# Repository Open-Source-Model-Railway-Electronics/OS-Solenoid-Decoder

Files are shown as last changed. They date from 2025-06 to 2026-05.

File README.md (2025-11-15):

# OS-Solenoid-Decoder

The OS-Solenoid-Decoder is a simple, powerful DCC accessory decoder for switching:

• Turnouts (point motors),  
• Relays,  
• Uncouplers,  
• And other solenoid-driven devices.  

It can handle loads of up to 5 amps and supports almost any type of point motor.  
It can also be used in combination with OS-relays to handle frog polarisation for electrofrog and unifrog points.  

This decoder is designed to be:

• Easy to wire — with pluggable screw terminals,  
• Easy to configure — using only standard DCC accessory commands,  
• Modular — with optional relay and transistor expansion boards,  
• And robust — with built-in overload protection.  

Whether you're building a large layout or just want something that works without hassle:  
this decoder is made to get the job done, without needing a degree in electronics.

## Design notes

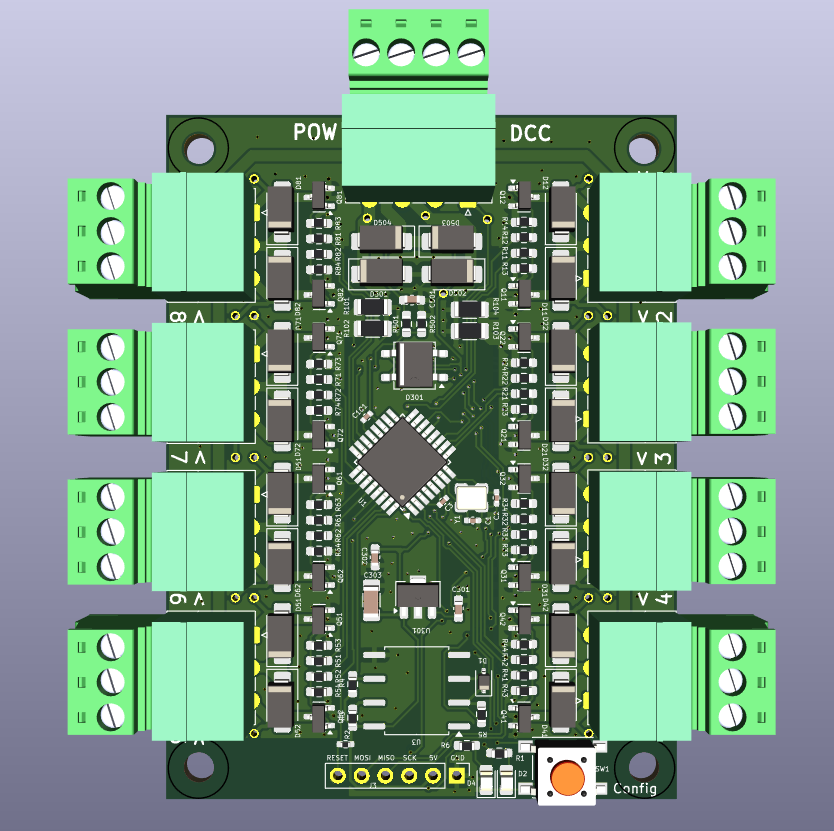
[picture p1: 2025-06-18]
hardware/OS-Solenoid-Decoder.png

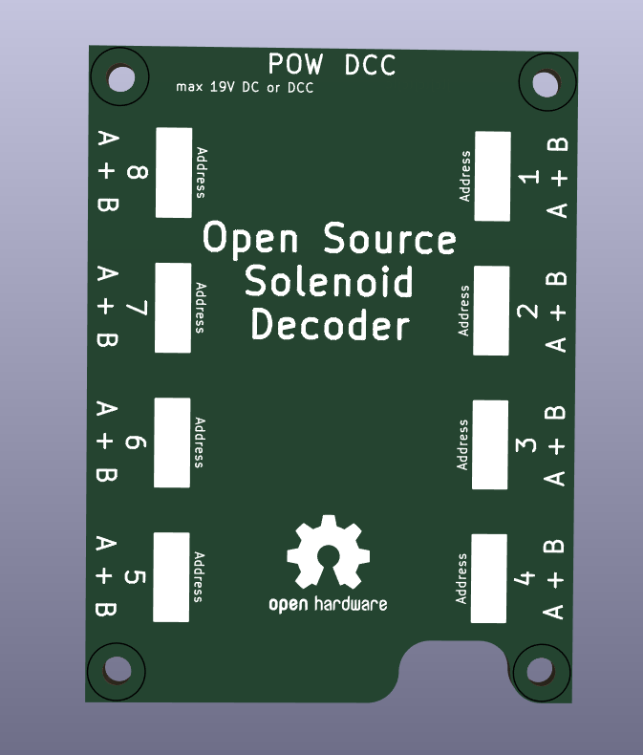
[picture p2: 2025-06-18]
hardware/OS-Solenoid-Decoder2.png

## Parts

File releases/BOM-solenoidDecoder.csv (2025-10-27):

Comment | Designator | Footprint | LCSC
6N137 | U3 | SOP-8_6.62x9.15mm_P2.54mm | C110020
Crystal_GND2 | Y1 | crystal_arduino | C13738
100nF | C302,C501 | C_0603_1608Metric_Pad1.08x0.95mm_HandSolder | C14663
ATmega328-A | U1 | TQFP-32_7x7mm_P0.8mm | C14877
100uF | C303 | C_1206_3216Metric_Pad1.33x1.80mm_HandSolder | C15008
12pF | C1,C2 | C_0402_1005Metric_Pad0.74x0.62mm_HandSolder | C1547
330nF | C301 | C_0603_1608Metric_Pad1.08x0.95mm_HandSolder | C1615
AO3400A | Q11,Q12,Q21,Q22,Q31,Q32,Q41,Q42,Q51,Q52,Q61,Q62,Q71,Q72,Q81,Q82 | SOT-23 | C20917
D | D1 | D_SOD-323 | C2128
1k5 | R5 | R_0603_smalltext | C22843
22R | R11,R12,R21,R22,R31,R32,R41,R42,R51,R52,R61,R62,R71,R72,R81,R82 | R_0603_1608Metric_Pad0.98x0.95mm_HandSolder | C23345
MB10S | D301 | TO-269AA | C2488
0R1 | R101,R102,R103,R104 | R_1206_3216Metric | C25334
10k | R2 | R_0402_1005Metric_Pad0.72x0.64mm_HandSolder | C25744
10k | R1,R13,R14,R23,R24,R3,R33,R34,R4,R43,R44,R502,R53,R54,R63,R64,R73,R74,R83,R84 | R_0603_smalltext | C25804
47k | R501 | R_0603_smalltext | C25819
100nF | C101,C3 | C_0402_1005Metric | C307331
SW_SPST | SW1 | tactile_SMD_6mm | C381050
6k2 | R6 | R_0603_1608Metric_Pad0.98x0.95mm_HandSolder | C4260
L78L05_SOT89 | U301 | SOT-89-3 | C42738
LED | D2,D4 | LED_0805_2012Metric_Pad1.15x1.40mm_HandSolder | C84256
SS34 | D11,D12,D21,D22,D31,D32,D41,D42,D501,D502,D503,D504,D51,D52,D61,D62,D71,D72,D81,D82 | D_SMA | C8678
~ | J11,J21,J31,J41,J51,J61,J71,J81 | PhoenixContact_MC_1,5_3-G-3.5_1x03_P3.50mm_Horizontal | C880573
Screw_Terminal_01x04 | J62 | PhoenixContact_MC_1,5_4-G-3.5_1x04_P3.50mm_Horizontal | C880574

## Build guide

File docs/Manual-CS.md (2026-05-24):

> 🌐 &nbsp; [🇬🇧 EN](Manual-EN.md) &nbsp;|&nbsp; [🇩🇪 DE](Manual-DE.md) &nbsp;|&nbsp; [🇫🇷 FR](Manual-FR.md) &nbsp;|&nbsp; [🇳🇱 NL](Manual-NL.md) &nbsp;|&nbsp; [🇪🇸 ES](Manual-ES.md) &nbsp;|&nbsp; [🇮🇹 IT](Manual-IT.md) &nbsp;|&nbsp; [🇵🇱 PL](Manual-PL.md) &nbsp;|&nbsp; 🇨🇿 CS &nbsp;|&nbsp; [🇩🇰 DA](Manual-DA.md) &nbsp;|&nbsp; [🇳🇴 NO](Manual-NO.md) &nbsp;|&nbsp; [🇸🇪 SV](Manual-SV.md) &nbsp;|&nbsp; [🇭🇺 HU](Manual-HU.md) &nbsp;|&nbsp; [🇵🇹 PT](Manual-PT.md)

# OS-Solenoid-Decoder

## 📘 Úvod

OS-Solenoid-Decoder je jednoduchý, výkonný DCC příslušenský dekodér pro přepínání:

- Výhybek (pohony výhybek)
- Relé
- Odpojovačů
- Jakéhokoli jiného solenoidem řízeného zařízení

Zvládá zatížení až 5 ampér a podporuje téměř jakýkoli typ pohonu výhybky.
Lze jej také kombinovat s OS-relays pro polarizaci srdcovky u výhybek electrofrog i unifrog.

Tento dekodér je navržen jako:

- **Snadný na zapojení** — zásuvné šroubové svorky usnadňují předpřipravení a umožňují rychlé vyjmutí nebo výměnu
- **Snadný na konfiguraci** — používá pouze standardní DCC příslušenské příkazy; bez počítače, bez CV, bez POM
- **Modulární** — volitelné rozšiřující desky relé a tranzistorů
- **Robustní** — vestavěná ochrana proti přetížení

Ať stavíte velké kolejiště nebo chcete jen něco, co funguje bez potíží: tento dekodér je stvořen k tomu, aby splnil úkol.

---

## Obsah

- [Vlastnosti](#-vlastnosti)
- [Připojení dekodéru](#-připojení-dekodéru)
- [Napájení](#-napájení)
- [Solenoidové výstupy](#-solenoidové-výstupy)
- [Relé rozšíření – polarizace Unifrog](#-relé-rozšíření--polarizace-unifrog)
- [Relé rozšíření – polarizace Electrofrog](#-relé-rozšíření--polarizace-electrofrog)
- [Relé rozšíření – otevřený kontakt (víceúčelový)](#️-relé-rozšíření--otevřený-kontakt-víceúčelový)
- [Odpojovače a jiné indukční zátěže](#-odpojovače-a-jiné-indukční-zátěže)
- [Konfigurace OS-Solenoid-Decoder](#️-konfigurace-os-solenoid-decoder)
- [Chování LED v provozním režimu](#-chování-led-v-provozním-režimu)
- [Vstup do konfiguračního režimu](#-vstup-do-konfiguračního-režimu)
- [Než začnete](#-než-začnete)
- [Přehled menu](#-přehled-menu)
- [Menu 1: Přiřazení DCC adres](#-menu-1-přiřazení-dcc-adres)
- [Menu 2: Výběr typu výstupu](#-menu-2-výběr-typu-výstupu)
- [Menu 3: Konfigurace doby impulzu](#-menu-3-konfigurace-doby-impulzu)
- [Menu 4: Pracovní cyklus PWM](#-menu-4-pracovní-cyklus-pwm)
- [Menu 5: Globální nastavení a předvolby](#-menu-5-globální-nastavení-a-předvolby)
- [Vysvětlení ovládání lokomotivními funkcemi](#-vysvětlení-ovládání-lokomotivními-funkcemi)

---

## 🔧 Vlastnosti

- **Celkový výstupní proud až 5 A** — pohání výkonné solenoidy, relé nebo pohony výhybek bez externích zesilovačů
- **Zásuvné šroubové svorky** — usnadňují předpřipravení a umožňují rychlé vyjmutí nebo výměnu dekodéru
- **Více výstupních režimů:**
  - Dvojitý impulz (výchozí)
  - Jednoduchý impulz
  - Dvojitý trvalý
  - Jednoduchý trvalý
  - Dvojitý impulz s relé Electrofrog
- **Jeden výstup najednou** — dekodér přepíná vždy jeden výstupní pár, aby předešel přetížení
- **Volitelná podpora modulu CDU** — snižuje spotřebu energie a prodlužuje životnost pohonu výhybky
- **Detekce a ochrana proti přetížení** — výstupy jsou automaticky deaktivovány při detekci přetížení
- **Konfigurace pouze prostřednictvím DCC příkazů** — není potřeba programovací software ani hardware
- **Předdefinované konfigurační předvolby** — rychle přepněte všechny výstupy na impulzní, trvalý nebo electrofrog režim jediným DCC příkazem
- **Ovládání lokomotivními funkcemi** (F1–F16) — pro rychlé přepínání pomocí ovladačů jako Roco Lokmaus nebo Multimaus
- **Podpora Roco adresového offsetu** — vestavěná podpora pro Roco 4-adresový offset
- **Rozšiřitelné relé a tranzistorovými deskami:**
  - Dvojitý relé modul pro polarizaci výhybky electrofrog
  - Jednoduché aretační relé pro přepínání polarity unifrog
  - Relé moduly s otevřeným kontaktem pro víceúčelové DCC relé ovládání
  - Tranzistorový budič pro dvouvodičové pohony výhybek

---

## 🔌 Připojení dekodéru

OS-Solenoid-Decoder se řídí přehledným a konzistentním schématem zapojení. Napájení je připojeno nahoře, výstupy jsou na obou stranách.

---

## 🔋 Napájení

- Připojte kolejové napětí DCC nebo DC napájení (max. 19 V) k dekodéru.
- Jak DCC signál, tak napájecí vodiče se připojují z horní strany dekodéru.
- ⚠️ Nepoužívejte AC napětí — poškodí dekodér.

---

## ⚡ Solenoidové výstupy

Dekodér poskytuje 8 dvojitých výstupních bloků navržených pro klasické dvousmyčkové pohony výhybek.

Každý výstupní blok má:

- Dvě vnější šroubové svorky — pro levou a pravou cívku (A a B)
- Jednu středovou svorku — pro společný vodič (COM), sdílený mezi oběma cívkami

Toto schéma umožňuje:

- Pohánět až 8 dvousmyčkových pohonů výhybek (např. PECO, Fleischmann, Märklin, Roco, Piko, Hornby)
- Nebo přímo připojit 3-vodičové pohony výhybek jako MTB MP-1

Výstupy jsou seskupeny v párech s jasným označením A, COM a B.

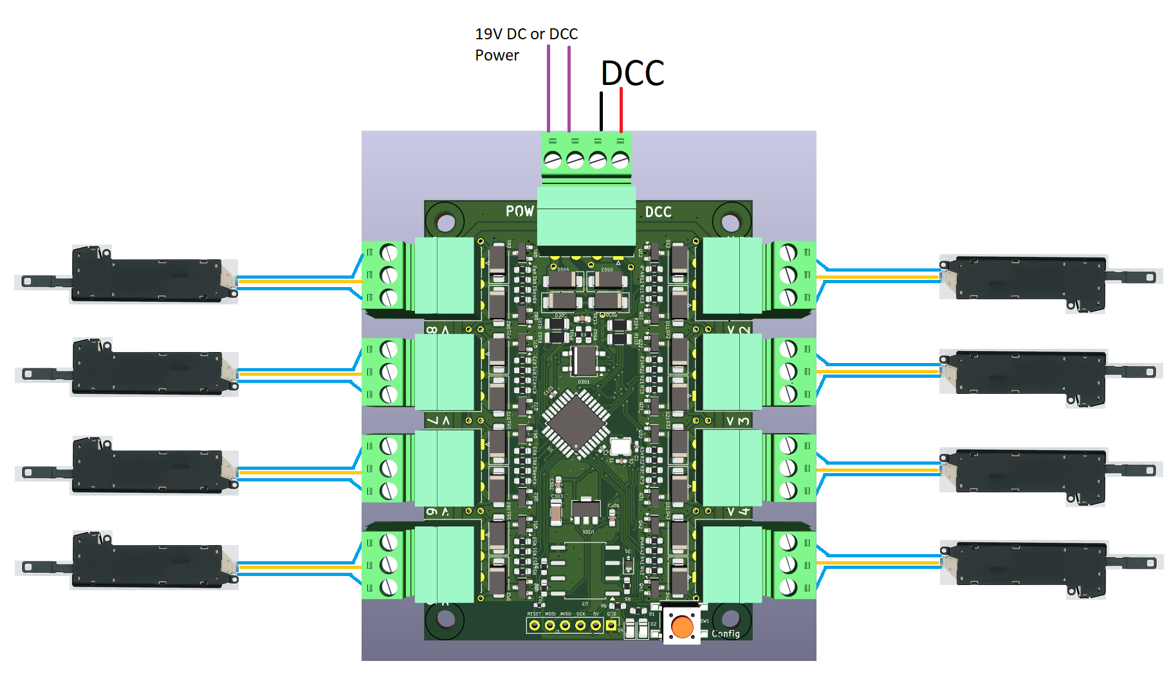
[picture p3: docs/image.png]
Solenoidový dekodér s 8 připojenými dvousmyčkovými pohony výhybek


Ačkoli dekodér není navržen pro ovládání návěstidel, může pohánět jednoduché dvouaspektové návěstidla pomocí stejných výstupů.

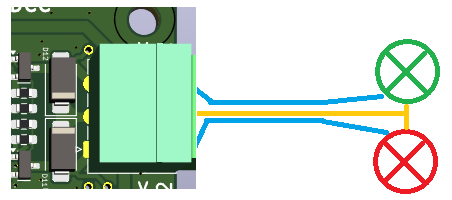
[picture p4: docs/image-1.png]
Příklad zapojení dvouaspektového návěstidla


---

## 🔌 Relé rozšíření – polarizace Unifrog

Toto rozšíření automaticky napájí srdcovku výhybek unifrog pomocí samoaretačních relé.

- Relé deska se skládá ze čtyř malých relé jednotek, které lze odlomit, pokud potřebujete méně než čtyři.

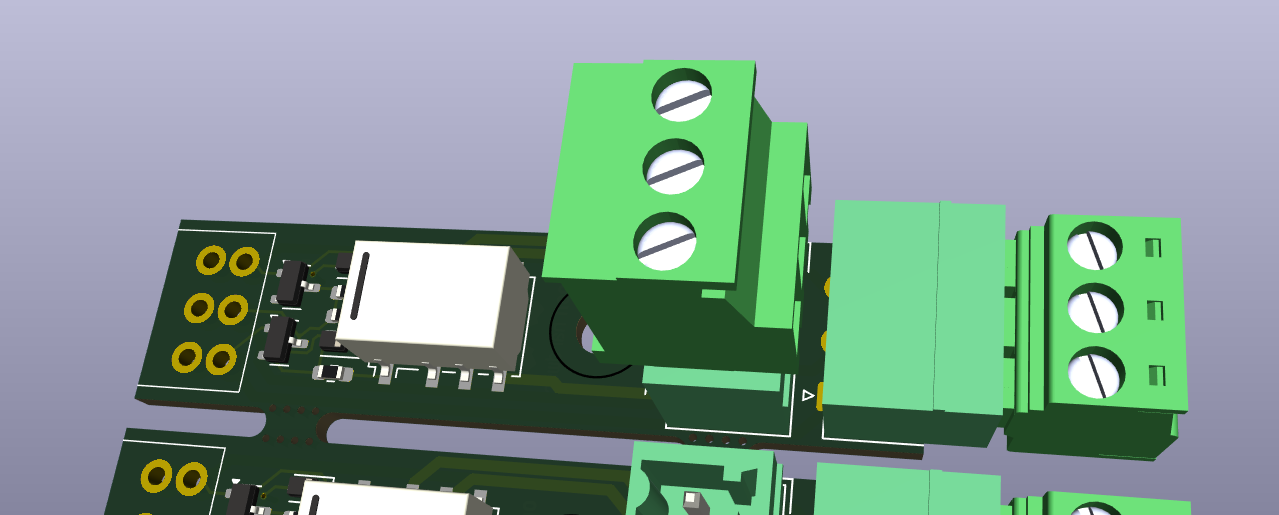
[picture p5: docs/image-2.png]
Aretační relé rozšiřující deska


- Relé jsou aretována stejným signálem, který spouští pohon výhybky — není potřeba žádná extra konfigurace.
- Každá relé jednotka přepíná polaritu srdcovky podle směru výhybky.

S jedním relé na výhybku toto rozšíření zvládá až 8 srdcovek unifrog pomocí dvou desek.

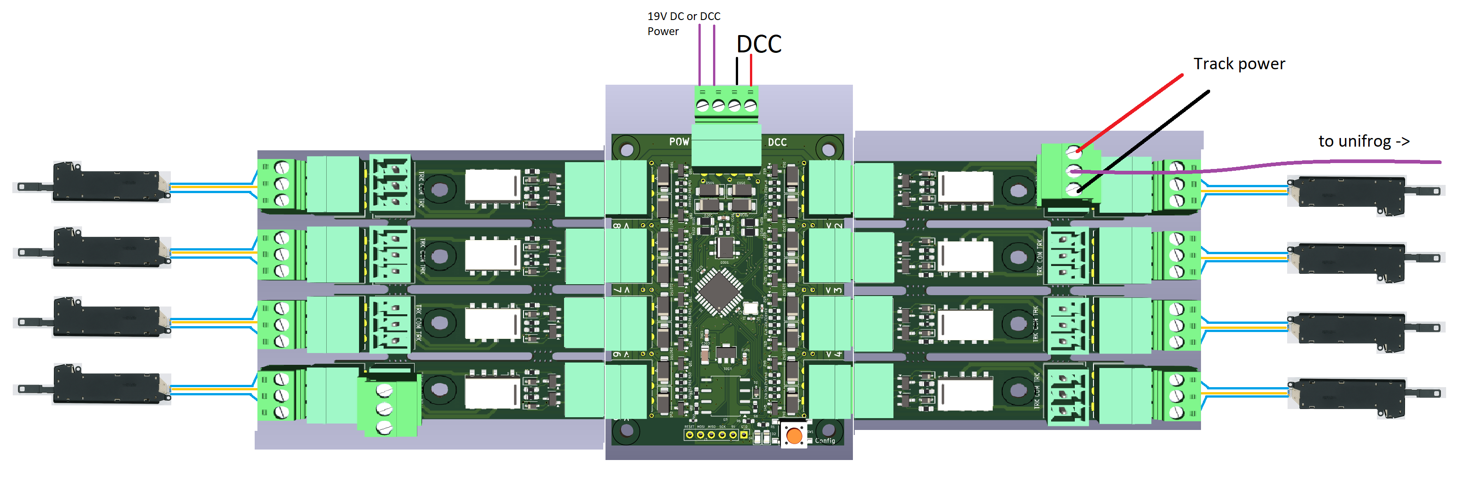
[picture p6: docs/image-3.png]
Relé rozšíření namontované na dekodér pro zapojení unifrog


- Relé deska se přímo zapojuje do rozšiřovacího záhlaví dekodéru, ale lze ji také namontovat vzdáleně poblíž výhybky.

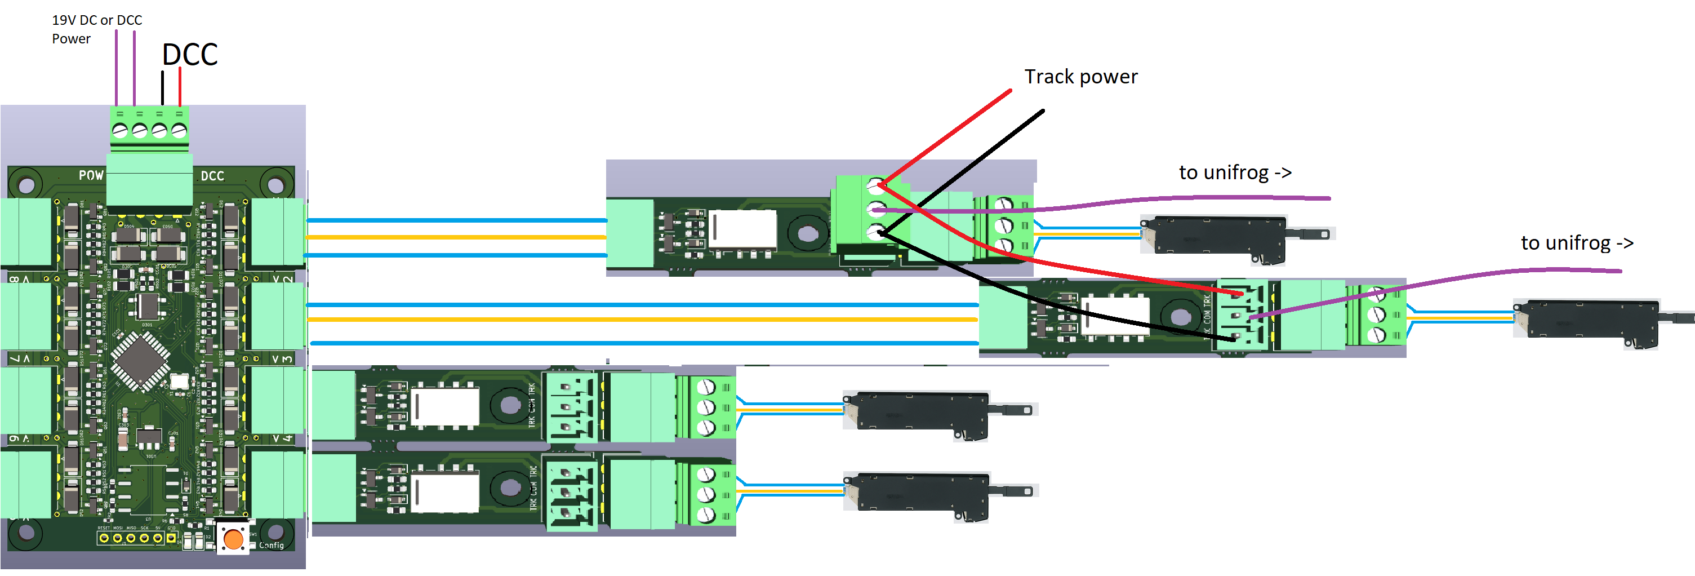
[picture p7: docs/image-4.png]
Příklad vzdáleně namontovaného relé rozšíření


Tento relé modul je také kompatibilní s jinými solenoidovými dekodéry.

---

## ⚡ Relé rozšíření – polarizace Electrofrog

Výhybky Electrofrog vyžadují dvě relé spínací operace na výhybku:

1. Jedno pro odpojení srdcovky před přehozením pohonu výhybky
2. Jedno pro opětovné připojení se správnou polaritou poté

Toto rozšíření zpracovává tuto sekvenci automaticky. Skládá se ze čtyř dvojitých relé modulů, trvale propojených.

- Zapojuje se do levé strany dekodéru (označené pro použití s electrofrog).
- Každý pár relé je propojen s jedním solenoidovým výstupem: výstup 1 → pár relé 1, výstup 2 → pár relé 2 atd.
- Tyto moduly nelze oddělovat, protože sdílejí kolejové napájení a interní logiku.

Dekodér má speciální předvolbu, která aktivuje přepínací sekvenci electrofrog.
Pokud je polarita srdcovky po instalaci nesprávná, obraťte přepínače na relé modulu pro opravu — není potřeba žádné přeprogramování.

---

## ⚙️ Relé rozšíření – otevřený kontakt (víceúčelový)

Pro přepínání externích zařízení (světla, návěstidla, logické obvody) pomocí prostých relé kontaktů:

- Každá jednotka poskytuje přepínací (NO/NC) relé, ovládatelné přes DCC.
- Až 16 individuálně adresovatelných relé kontaktů při plném osazení.
- Moduly se přímo zapojují do dekodéru nebo lze je použít vzdáleně s vodiči.
- Dostupné ve verzi s průchozím montáží pro kutily a v kompaktní verzi SMD.

Stejně jako relé desky unifrog lze tyto moduly odlomit a znovu použít s jinými DCC solenoidovými dekodéry.

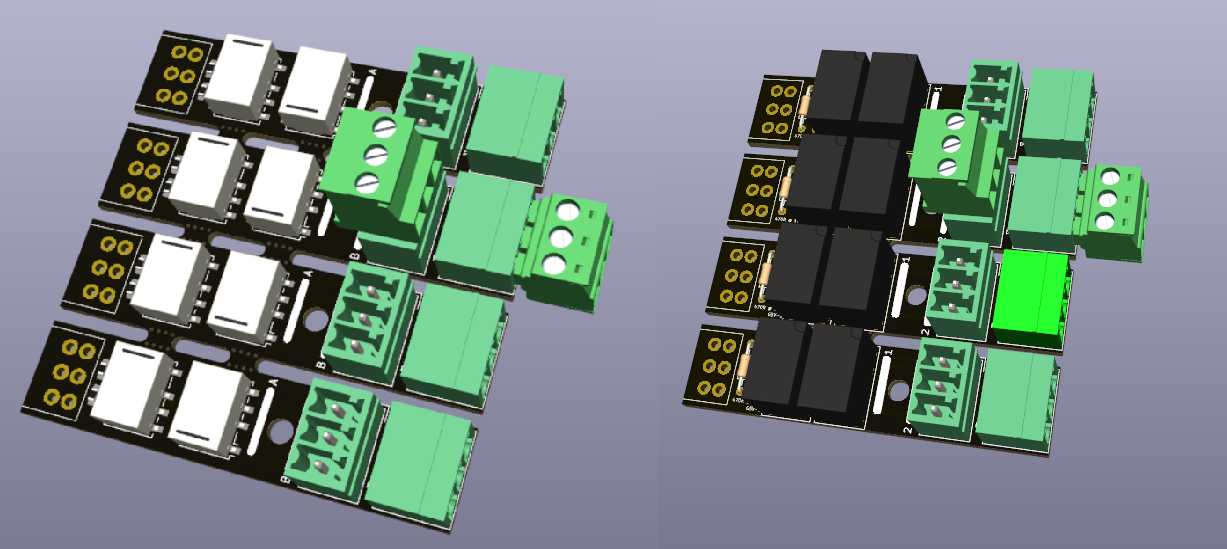
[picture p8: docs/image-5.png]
Víceúčelové relé moduly namontované na dekodér


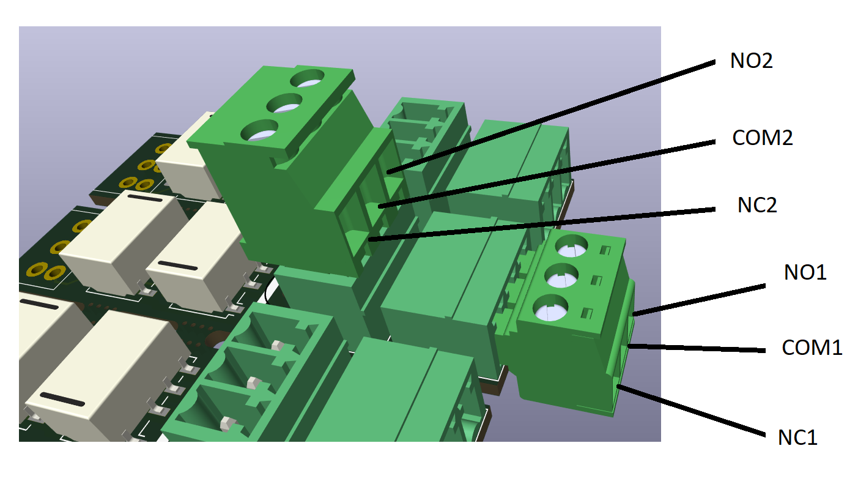
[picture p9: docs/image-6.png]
Detail víceúčelového relé modulu


Víceúčelové relé rozšíření může také polarizovat výhybky electrofrog s mírně složitějším zapojením:

- Použijte kontakty NO (Normally Open)
- Propojte oba kontakty COM dohromady a připojte je ke srdcovce
- Připojte kontakty NO k napájecím kolejnicím

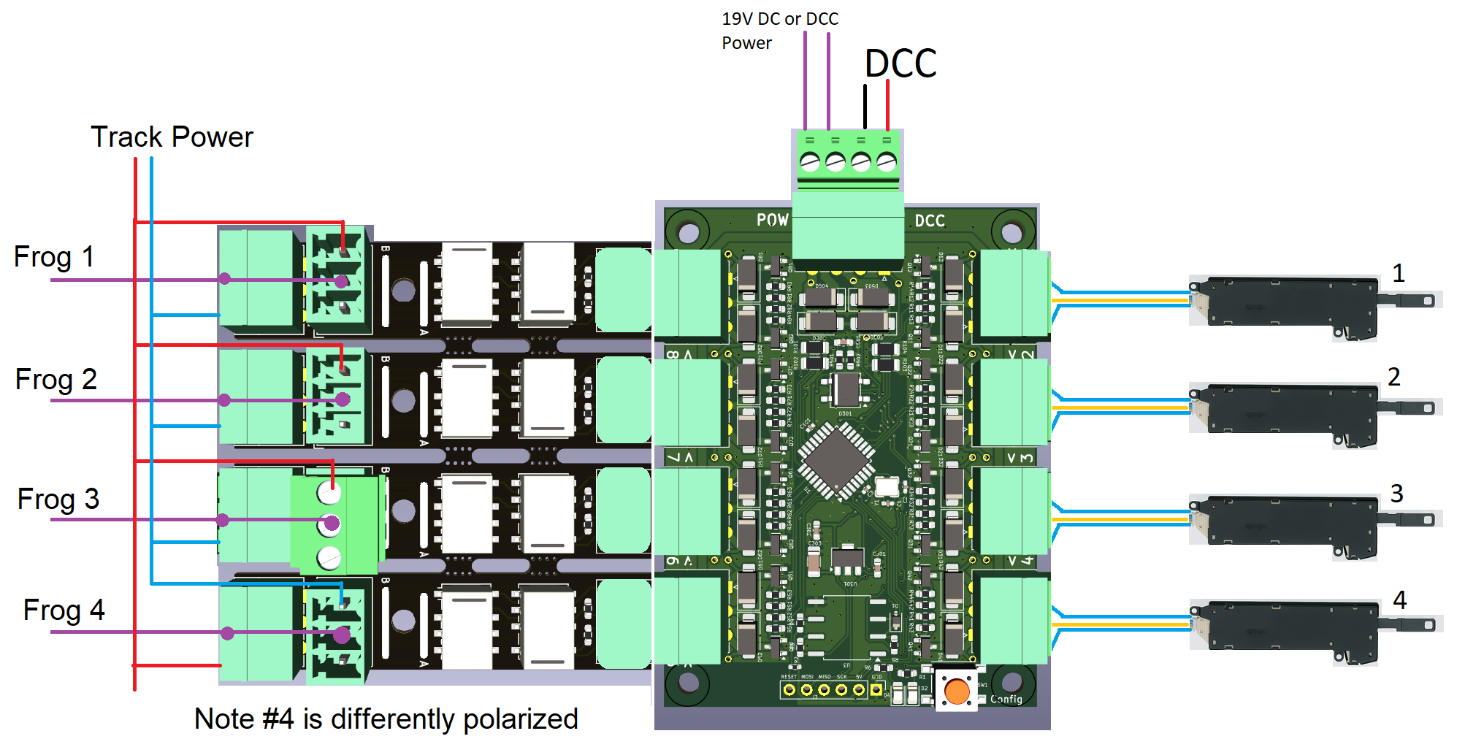
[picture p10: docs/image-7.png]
Zapojení electrofrog pomocí víceúčelových relé modulů


Pokud má srdcovka nesprávnou polaritu, prohoďte dva napájecí vodiče kolejnic (jak je znázorněno pro srdcovku 4 ve výše uvedeném schématu).

---

## 🧲 Odpojovače a jiné indukční zátěže

OS-Solenoid-Decoder může pohánět odpojovače, elektromagnety a jiné indukční zátěže kromě pohonů výhybek.

- **Režim jednoduchého impulzu** (doporučeno) — vysílá krátký proud, ideální pro cívky s pružinou nebo časově citlivé cívky
- **Režim jednoduchého trvalého** — udržuje výstup trvale zapnutý, užitečné pro monostabilní relé nebo jednoduché ZAP/VYP zařízení

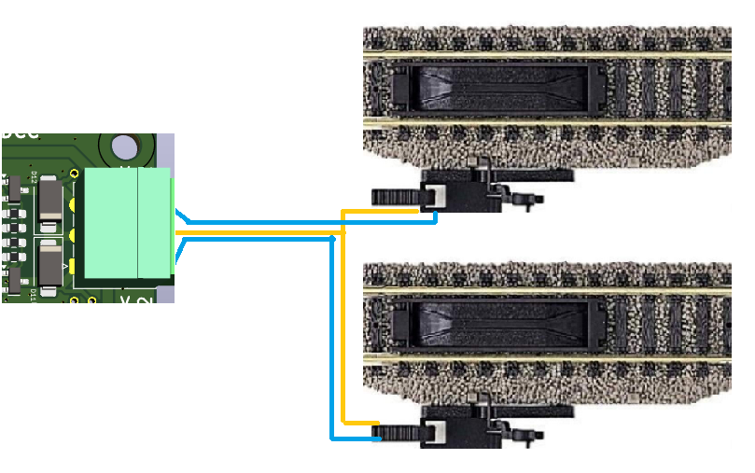
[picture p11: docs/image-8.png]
Příklad zapojení odpojovače


⚠️ Odpojovače se mohou přehřát při příliš dlouhém přepnutí — vždy kontrolujte datový list pro vaši značku koleje a udržujte dobu impulzu krátkou.

---

## ⚙️ Konfigurace OS-Solenoid-Decoder

Ve výchozím stavu dekodér pracuje v normálním režimu při zapnutí. Dvě LED poskytují vizuální zpětnou vazbu o tom, co se děje.

---

## 🔦 Chování LED v provozním režimu

| Vzor LED | Režim |
|---|---|
| Obě LED blikají | Dvojitý impulz (výchozí) |
| Jedna LED bliká, druhá ZHASNUTÁ | Jednoduchý impulz |
| Obě LED SVÍTÍ | Dvojitý trvalý |
| Jedna LED SVÍTÍ | Jednoduchý trvalý |
| Jedna LED SVÍTÍ + druhá LED bliká | Režim Electrofrog (dvojitý impulz + relé srdcovky) |

Pokud jsou výstupy nakonfigurovány se smíšenými typy, levá LED zůstane SVÍTIT a pravá LED bude nepřetržitě jednou blikat, aby indikovala smíšený konfigurační režim.

---

## 🧰 Vstup do konfiguračního režimu

Pro vstup do konfiguračního režimu:

1. Podržte konfigurační tlačítko. Pravá LED začne blikat:
   - 1 bliknutí = Menu 1
   - 2 bliknutí = Menu 2
   - ... až do Menu 5
2. Uvolněte tlačítko, když LED dosáhne požadovaného menu.

Po vstupu do menu:

- Levá LED bliká stejný počet bliknutí jako číslo menu (např. 3 bliknutí = Menu 3).
- Stiskněte tlačítko znovu pro ukončení menu, pokud níže uvedená sekce neříká jinak.

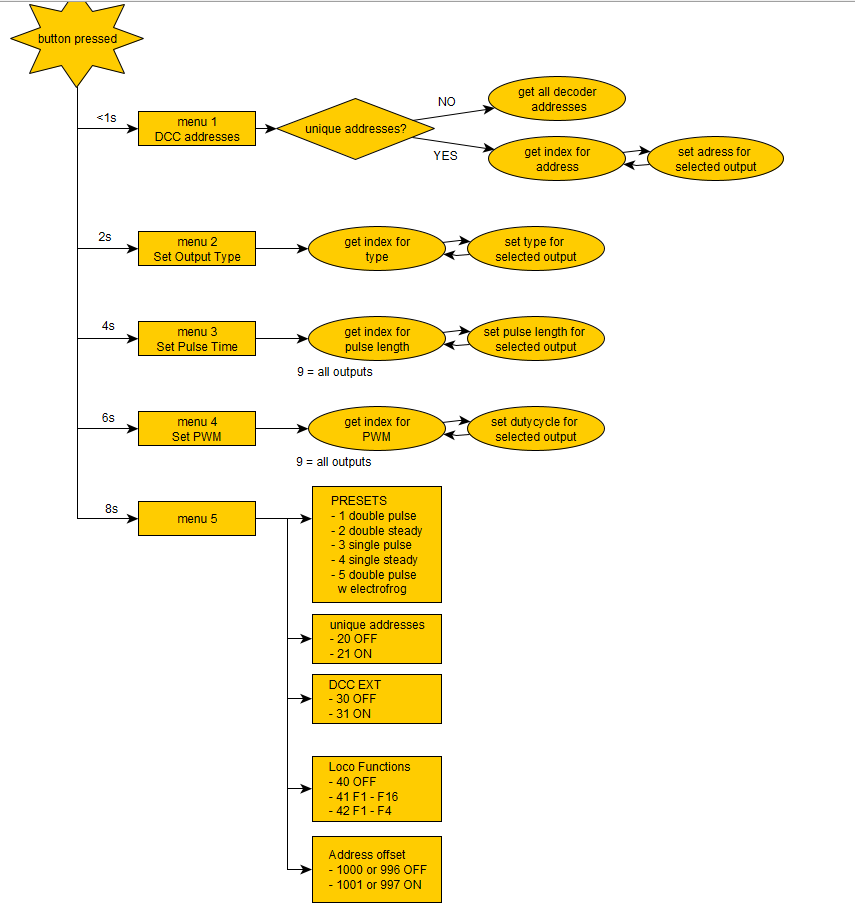
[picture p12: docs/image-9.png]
Vývojový diagram konfiguračního menu


---

## 🧠 Než začnete

Pokud plánujete používat smíšené typy výstupů (např. Jednoduchý trvalý pro relé vedle Dvojitého impulzu pro pohony výhybek), naplánujte si přiřazení výstupů nejprve na papíře.

**Příklad:** pokud výstupy 5–8 mají být Jednoduchý trvalý (pro 8 relé) a výstupy 1–4 mají být Dvojitý trvalý (pro pohony výhybek), musíte:

1. Použít Menu 2 pro přiřazení správných typů výstupů
2. Poté použít Menu 1 pro pečlivé přiřazení DCC adres, protože jednoduché výstupy používají více adres

---

## 📖 Přehled menu

| Menu | Funkce |
|---|---|
| 1 | Přiřazení DCC adres |
| 2 | Výběr typu výstupu |
| 3 | Konfigurace doby impulzu |
| 4 | Pracovní cyklus PWM |
| 5 | Globální nastavení a předvolby |

---

## 🟠 Menu 1: Přiřazení DCC adres

Toto menu slouží k přiřazení DCC adres každému výstupu.

Pravidla:
- Dvojité režimy používají 1 adresu
- Jednoduché režimy používají 2 adresy (A a B samostatně)

Pokud přiřadíte adresu 20 k výstupu 1 v jednoduchém režimu, zabere adresy 20 a 21. Výstup 2 pak začne na adrese 22. Dekodér toto posouvání zpracovává automaticky.

Výběr výstupů:
- Odešlete DCC příslušenskou adresu 1–8 pro výběr výstupu.
- Odešlete druhou adresu pro přiřazení k danému výstupu.
- Odešlete adresu 9 jako volič pro okamžité použití stejné adresy na všechny výstupy.

V režimu jedinečného adresování můžete přiřadit každému výstupu vlastní adresu včetně opakovaných nebo přeskočených čísel. Dekodér se okamžitě vrátí do provozního režimu po přiřazení, pokud není aktivní jedinečný režim — v tom případě stiskněte konfigurační tlačítko pro ukončení.

---

## 🟡 Menu 2: Výběr typu výstupu

Každý výstup lze nastavit na jeden z následujících typů:

| ID typu | Popis režimu |
|---|---|
| 1 | Dvojitý impulz (výchozí) |
| 2 | Dvojitý trvalý |
| 3 | Jednoduchý impulz |
| 4 | Jednoduchý trvalý |
| 5 | Dvojitý impulz s podporou relé Electrofrog |

V režimu Electrofrog ovládají výstupy 1–4 páry relé na výstupech 8–5 v opačném pořadí (výstup 1 → relé 8, výstup 2 → relé 7 atd.).

Vyberte výstup ke konfiguraci odesláním DCC adresy 1–8.

---

## 🔵 Menu 3: Konfigurace doby impulzu

Doladění doby impulzu pro každý výstup.

**Výstupy s jednoduchým impulzem:**
- Čas se nastavuje v celých sekundách
- Adresa 10 = 10 sekund
- Rozsah: 1–4096 sekund
- Výchozí: 5 s

**Výstupy s dvojitým impulzem:**
- Čas se nastavuje v krocích po 10 ms
- Adresa 1 = 10 ms
- Maximum: 40,9 s (4096 × 10 ms)
- Výchozí: 50 ms

Odešlete adresu 9 pro okamžité použití stejného času na všechny výstupy.

---

## 🟣 Menu 4: Pracovní cyklus PWM

Dostupné pro výstupy nakonfigurované v trvalém režimu (jednoduchém nebo dvojitém).

PWM snižuje průměrný dodávaný výkon — ideální pro pomalé motory jako MTB MP-1.

- Frekvence PWM: 50 Hz
- Adresa 10 = 100% pracovní cyklus (výchozí; plný výkon, bez PWM)

| Adresa | Pracovní cyklus |
|---|---|
| 1 | 10 % |
| 2 | 20 % |
| ... | ... |
| 10 | 100 % (výchozí) |

Odešlete adresu 9 pro použití stejného pracovního cyklu na všechny výstupy.

---

## 🔘 Menu 5: Globální nastavení a předvolby

**Předvolby — nastavení všech typů výstupů najednou:**

| Adresa | Předvolba |
|---|---|
| 1 | Dvojitý impulz (výchozí) |
| 2 | Dvojitý trvalý |
| 3 | Jednoduchý impulz |
| 4 | Jednoduchý trvalý |
| 5 | Dvojitý impulz s režimem Electrofrog |

**Speciální možnosti:**

| Adresa | Nastavení |
|---|---|
| 20 | Zakázat jedinečné adresy výstupů (výchozí) |
| 21 | Povolit jedinečné adresy výstupů |
| 30 | Zakázat podporu příkazů DCC EXT (výchozí) |
| 31 | Povolit podporu délky impulzu DCC EXT |
| 40 | Zakázat ovládání lokomotivními funkcemi (výchozí) |
| 41 | Povolit lokomotivní funkce (F1–F16, 1 adresa) |
| 42 | Povolit lokomotivní funkce (F1–F4, 2+ adresy) |
| 996 / 1000 | Zakázat Roco 4-adresový offset (výchozí) |
| 997 / 1001 | Povolit Roco 4-adresový offset |

---

## 📟 Vysvětlení ovládání lokomotivními funkcemi

Dekodér lze ovládat pomocí funkčních kláves lokomotivy (F1–F16) místo DCC příslušenských příkazů.

**Výhody:**
- Funguje s ovladači jako Roco Lokmaus 2
- Velmi rychlé přepínání — ideální pro rychlé ovládání kolejiště

**Režimy:**
- **Režim F1–F16:** používá 1 adresu lokomotivy
- **Režim F1–F4:** používá 2 nebo více adres lokomotivy (užitečné pro ovladače, které podporují pouze F1–F4)

Použitá adresa lokomotivy odpovídá DCC adrese přiřazené k výstupu 1.

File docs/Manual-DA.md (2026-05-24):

> 🌐 &nbsp; [🇬🇧 EN](Manual-EN.md) &nbsp;|&nbsp; [🇩🇪 DE](Manual-DE.md) &nbsp;|&nbsp; [🇫🇷 FR](Manual-FR.md) &nbsp;|&nbsp; [🇳🇱 NL](Manual-NL.md) &nbsp;|&nbsp; [🇪🇸 ES](Manual-ES.md) &nbsp;|&nbsp; [🇮🇹 IT](Manual-IT.md) &nbsp;|&nbsp; [🇵🇱 PL](Manual-PL.md) &nbsp;|&nbsp; [🇨🇿 CS](Manual-CS.md) &nbsp;|&nbsp; 🇩🇰 DA &nbsp;|&nbsp; [🇳🇴 NO](Manual-NO.md) &nbsp;|&nbsp; [🇸🇪 SV](Manual-SV.md) &nbsp;|&nbsp; [🇭🇺 HU](Manual-HU.md) &nbsp;|&nbsp; [🇵🇹 PT](Manual-PT.md)

# OS-Solenoid-Decoder

## 📘 Introduktion

OS-Solenoid-Decoder er en enkel, kraftfuld DCC-tilbehørsdekoder til skift af:

- Sporskifter (sporskiftemotorer)
- Relæer
- Afkoblere
- Enhver anden solenoid-drevet enhed

Den kan håndtere belastninger på op til 5 A og understøtter næsten enhver type sporskiftemotor.
Den kan også bruges i kombination med OS-relæer til at håndtere hjertestykke-polarisering for både Electrofrog- og Unifrog-sporskifter.

Denne dekoder er designet til at være:

- **Nem at kabelforbinde** — tilsluttbare skrueterminaler gør forudkabeltrækning ligetil og muliggør hurtig fjernelse eller udskiftning
- **Nem at konfigurere** — bruger udelukkende standard DCC-tilbehørskommandoer; ingen computer, ingen CV, ingen POM
- **Modulær** — valgfrie relæ- og transistorudvidelseskort
- **Robust** — indbygget overbelastningsbeskyttelse

Uanset om du bygger et stort anlæg eller bare ønsker noget, der fungerer uden besvær: denne dekoder er lavet til at klare opgaven.

---

## Indholdsfortegnelse

- [Egenskaber](#-egenskaber)
- [Tilslutning af dekoderen](#-tilslutning-af-dekoderen)
- [Strømforsyning](#-strømforsyning)
- [Solenoid-udgange](#-solenoid-udgange)
- [Relæudvidelse – Unifrog-polarisering](#-relæudvidelse--unifrog-polarisering)
- [Relæudvidelse – Electrofrog-polarisering](#-relæudvidelse--electrofrog-polarisering)
- [Relæudvidelse – Åben kontakt (general purpose)](#️-relæudvidelse--åben-kontakt-general-purpose)
- [Afkoblere og andre induktive belastninger](#-afkoblere-og-andre-induktive-belastninger)
- [Konfiguration af OS-Solenoid-Decoder](#️-konfiguration-af-os-solenoid-decoder)
- [LED-adfærd i driftstilstand](#-led-adfærd-i-driftstilstand)
- [Adgang til konfigurationstilstand](#-adgang-til-konfigurationstilstand)
- [Inden du starter](#-inden-du-starter)
- [Menooversigt](#-menooversigt)
- [Menu 1: DCC-adressetildeling](#-menu-1-dcc-adressetildeling)
- [Menu 2: Udgangstypevalg](#-menu-2-udgangstypevalg)
- [Menu 3: Pulstidskonfiguration](#-menu-3-pulstidskonfiguration)
- [Menu 4: PWM-arbejdscyklus](#-menu-4-pwm-arbejdscyklus)
- [Menu 5: Globale indstillinger og forudindstillinger](#-menu-5-globale-indstillinger-og-forudindstillinger)
- [Lokomotivfunktionsstyring forklaret](#-lokomotivfunktionsstyring-forklaret)

---

## 🔧 Egenskaber

- **Op til 5 A samlet udgangsstrøm** — driver tunge solenoider, relæer eller sporskiftemotorer uden eksterne boostere
- **Tilsluttbare skrueterminaler** — gør forudkabeltrækning nem og muliggør hurtig fjernelse eller udskiftning af dekoderen
- **Flere udgangstyper:**
  - Dobbelt puls (standard)
  - Enkelt puls
  - Dobbelt stabil
  - Enkelt stabil
  - Dobbelt puls med Electrofrog-relæ
- **Én udgang ad gangen** — dekoderen skifter ét udgangssæt ad gangen for at forhindre overbelastning
- **Valgfri CDU-modulunderstøttelse** — reducerer strømforbrug og forlænger sporskiftemotorens levetid
- **Overbelastningsdetektion og -beskyttelse** — udgange deaktiveres automatisk, hvis en overbelastning registreres
- **Konfiguration udelukkende via DCC-kommandoer** — ingen programmeringssoftware eller hardware påkrævet
- **Foruddefinerede konfigurationsforudindstillinger** — skift hurtigt alle udgange til puls-, stabil- eller Electrofrog-tilstand med en enkelt DCC-kommando
- **Lokomotivfunktionsstyring** (F1–F16) — til hurtig skift via styrenheder som Roco Lokmaus eller Multimaus
- **Roco-adresseforskydningsunderstøttelse** — indbygget understøttelse af Roco 4-adresse-forskydning
- **Udvidelsesmuligheder med relæ- og transistorkort:**
  - Dobbelt relæmodul til Electrofrog-sporskifte-polarisering
  - Enkelt selvholdende relæ til Unifrog-polaritetsskift
  - Åben-kontakt relæmoduler til general-purpose DCC-relæstyring
  - Transistordrivermodul til 2-trådede sporskiftemotorer

---

## 🔌 Tilslutning af dekoderen

OS-Solenoid-Decoder følger et klart og konsistent kabeltrækningslayout. Strøm tilsluttes øverst, udgange er på begge sider.

---

## 🔋 Strømforsyning

- Forbind enten DCC-skinnesænkning eller en DC-strømforsyning (maks. 19 V) til dekoderen.
- Både DCC-signalet og strømleredningerne tilsluttes fra dekodernes øverste side.
- ⚠️ Brug ikke AC-spænding — dette vil beskadige dekoderen.

---

## ⚡ Solenoid-udgange

Dekoderen leverer 8 dobbelte udgangsblokke, designet til klassiske toviklings-sporskiftemotorer.

Hvert udgangsblok har:

- To ydre skrueterminaler — til venstre og højre spole (A og B)
- Én midterterminal — til den fælles ledning (COM), delt mellem de to spoler

Dette layout giver dig mulighed for:

- At drive op til 8 toviklings-sporskiftemotorer (f.eks. PECO, Fleischmann, Märklin, Roco, Piko, Hornby)
- Eller forbinde 3-trådede sporskiftemotorer som MTB MP-1 direkte

Udgange er grupperet i par med klar A-, COM- og B-mærkning.

Solenoid-dekoder med 8 toviklings-sporskiftemotorer tilsluttet

Selvom dekoderen ikke er designet til signalstyring, kan den drive simple to-aspekt-signaler ved hjælp af de samme udgange.

Kabeltrækningseksempel for to-aspekt-signal

---

## 🔌 Relæudvidelse – Unifrog-polarisering

Denne udvidelse forsyner automatisk hjertestykket i Unifrog-sporskifter ved hjælp af selvholdende relæer.

- Relækortet består af fire små relæenheder, som kan knækkes fra hinanden, hvis du har brug for færre end fire.

Selvholdende relæudvidelseskort

- Relæerne aktiveres af det samme signal, der bruges til at udløse sporskiftemotoren — ingen ekstra konfiguration er nødvendig.
- Hver relæenhed skifter hjertestykke-polariteten baseret på sporskiftets retning.

Med ét relæ per sporskifte håndterer denne udvidelse op til 8 Unifrog-hjertestykker ved hjælp af to kort.

Relæudvidelse monteret på dekoder til Unifrog-kabeltrækning

- Relækortet sættes direkte ind i dekodernes udvidelsesheader, men kan også monteres eksternt nær sporskiftet.

Eksempel på eksternt monteret relæudvidelse

Dette relæmodul er også kompatibelt med andre solenoid-dekodere.

---

## ⚡ Relæudvidelse – Electrofrog-polarisering

Electrofrog-sporskifter kræver to relæskift per sporskifte:

1. Ét til at afbryde hjertestykket inden skift af sporskiftemotoren
2. Ét til at genoprette forbindelsen med den korrekte polaritet bagefter

Denne udvidelse håndterer den sekvens automatisk. Den består af fire dobbelte relæmoduler, der er permanent forbundne.

- Det sættes ind i venstre side af dekoderen (markeret til Electrofrog-brug).
- Hvert relæpar er koblet til én solenoid-udgang: udgang 1 → relæpar 1, udgang 2 → relæpar 2 osv.
- Disse moduler kan ikke adskilles, da de deler skinnestrøm og intern logik.

Dekoderen har en særlig forudindstillings-tilstand, der aktiverer Electrofrog-skiftsekvensen.
Hvis hjertestykke-polariteten er forkert efter installation, vend jumberne på relæmodulet for at rette det — ingen omprogrammering er nødvendig.

---

## ⚙️ Relæudvidelse – Åben kontakt (general purpose)

Til skift af eksterne enheder (lys, signaler, logikkredsløb) ved hjælp af rene relækontakter:

- Hver enhed leverer et dobbeltskift (NO/NC)-relæ, der kan styres via DCC.
- Op til 16 individuelt adresserbare relækontakter ved fuld bestyckning.
- Modulerne sættes direkte ind i dekoderen eller kan bruges eksternt med ledninger.
- Tilgængelig i en gennemhuls-DIY-version og en kompakt SMD-version.

Ligesom Unifrog-relækortene kan disse moduler knækkes fra hinanden og genbruges med andre DCC-solenoid-dekodere.

General-purpose relæmoduler monteret på dekoderen

Detail af general-purpose relæmodul

General Purpose-relæudvidelsen kan også polarisere Electrofrog-sporskifter med lidt mere kabeltrækning:

- Brug NO (Normally Open)-kontakterne
- Sæt begge COM-kontakter i sløjfe og forbind dem til hjertestykket
- Forbind NO-kontakterne til skinnestrømsshinnerne

Electrofrog-kabeltrækning ved hjælp af General Purpose-relæmoduler

Hvis et hjertestykke ender med forkert polaritet, byt de to skinnestrømsleredninger (som vist for hjertestykke 4 i diagrammet ovenfor).

---

## 🧲 Afkoblere og andre induktive belastninger

OS-Solenoid-Decoder kan drive afkoblere, elektromagneter og andre induktive belastninger ud over sporskiftemotorer.

- **Enkelt puls-tilstand** (anbefalet) — sender et kort strømudbrud, ideelt til fjederspændte eller tidsfølsomme spoler
- **Enkelt stabil-tilstand** — holder udgangen kontinuerligt tændt, nyttigt til monostabile relæer eller simple TIL/FRA-enheder

Afkoblerkabeltrækningseksempel

⚠️ Afkoblere kan overophede, hvis de tændes for længe — tjek altid dataarket for dit sporvarebrands og hold pulstiderne korte.

---

## ⚙️ Konfiguration af OS-Solenoid-Decoder

Som standard fungerer dekoderen i normal tilstand, når den tændes. To LED'er giver visuel tilbagemelding om, hvad der sker.

---

## 🔦 LED-adfærd i driftstilstand

| LED-mønster | Tilstand |
|---|---|
| Begge LED'er blinker | Dobbelt puls (standard) |
| Én LED blinker, én SLUKKET | Enkelt puls |
| Begge LED'er TÆNDt | Dobbelt stabil |
| Én LED TÆNDt | Enkelt stabil |
| Én LED TÆNDt + anden LED blinker | Electrofrog-tilstand (dobbelt puls + frog-relæ) |

Når udgange er konfigureret med blandede typer, forbliver venstre LED TÆNDt og højre LED blinker én gang kontinuerligt for at angive blandet-konfigurationstilstand.

---

## 🧰 Adgang til konfigurationstilstand

For at gå ind i konfigurationstilstand:

1. Hold konfigurationsknappen nede. Højre LED begynder at blinke:
   - 1 blink = Menu 1
   - 2 blink = Menu 2
   - ... op til Menu 5
2. Slip knappen, når LED'en når den menu, du ønsker.

Når du er i en menu:

- Venstre LED blinker det samme antal gange som menunummeret (f.eks. 3 blink = Menu 3).
- Tryk på knappen igen for at afslutte menuen, medmindre afsnittet nedenfor siger andet.

Konfigurationsmenu-flowdiagram

---

## 🧠 Inden du starter

Hvis du planlægger at bruge blandede udgangstyper (f.eks. Enkelt stabil til relæer sammen med Dobbelt puls til sporskiftemotorer), planlæg dine udgangstildelinger på papir først.

**Eksempel:** Hvis udgange 5–8 skal være Enkelt stabil (til 8 relæer) og udgange 1–4 skal være Dobbelt stabil (til sporskiftemotorer), skal du:

1. Bruge Menu 2 til at tildele de korrekte udgangstyper
2. Derefter bruge Menu 1 til omhyggeligt at tildele DCC-adresser, fordi enkeltudgange bruger flere adresser

---

## 📖 Menooversigt

| Menu | Funktion |
|---|---|
| 1 | DCC-adressetildeling |
| 2 | Udgangstypevalg |
| 3 | Pulstidskonfiguration |
| 4 | PWM-arbejdscyklus |
| 5 | Globale indstillinger og forudindstillinger |

---

## 🟠 Menu 1: DCC-adressetildeling

Brug denne menu til at tildele DCC-adresser til hver udgang.

Regler:
- Dobbelte tilstande bruger 1 adresse
- Enkle tilstande bruger 2 adresser (A og B separat)

Hvis du tildeler adresse 20 til udgang 1 i enkelt tilstand, vil den optage adresserne 20 og 21. Udgang 2 starter derefter ved 22. Dekoderen håndterer denne forskydning automatisk.

Valg af udgange:
- Send DCC-tilbehørsadresse 1–8 for at vælge en udgang.
- Send en anden adresse for at tildele den til den pågældende udgang.
- Send adresse 9 som vælger for at anvende den samme adresse på alle udgange på én gang.

I unik adresseringstilstand kan du give hver udgang en brugerdefineret adresse, herunder gentagne eller udeladte numre. Dekoderen vender tilbage til driftstilstand umiddelbart efter tildeling, medmindre unik tilstand er aktiv — i så fald tryk på konfigurationsknappen for at afslutte.

---

## 🟡 Menu 2: Udgangstypevalg

Hver udgang kan indstilles til en af følgende typer:

| Type-ID | Tilstandsbeskrivelse |
|---|---|
| 1 | Dobbelt puls (standard) |
| 2 | Dobbelt stabil |
| 3 | Enkelt puls |
| 4 | Enkelt stabil |
| 5 | Dobbelt puls med Electrofrog-relæunderstøttelse |

I Electrofrog-tilstand styrer udgange 1–4 relæparrene på udgange 8–5 i omvendt rækkefølge (udgang 1 → relæ 8, udgang 2 → relæ 7 osv.).

Vælg hvilken udgang der skal konfigureres ved at sende DCC-adresse 1–8.

---

## 🔵 Menu 3: Pulstidskonfiguration

Finjuster pulstiden for hver udgang.

**Enkelt puls-udgange:**
- Tid angives i hele sekunder
- Adresse 10 = 10 sekunder
- Område: 1–4096 sekunder
- Standard: 5 s

**Dobbelt puls-udgange:**
- Tid angives i trin på 10 ms
- Adresse 1 = 10 ms
- Maksimum: 40,9 s (4096 × 10 ms)
- Standard: 50 ms

Send adresse 9 for at anvende den samme tid på alle udgange på én gang.

---

## 🟣 Menu 4: PWM-arbejdscyklus

Tilgængelig for udgange konfigureret i stabil tilstand (enkelt eller dobbelt).

PWM reducerer den gennemsnitlige leverede effekt — ideel til langsomme motorer som MTB MP-1.

- PWM-frekvens: 50 Hz
- Adresse 10 = 100% arbejdscyklus (standard; fuld effekt, ingen PWM)

| Adresse | Arbejdscyklus |
|---|---|
| 1 | 10% |
| 2 | 20% |
| ... | ... |
| 10 | 100% (standard) |

Send adresse 9 for at anvende den samme arbejdscyklus på alle udgange.

---

## 🔘 Menu 5: Globale indstillinger og forudindstillinger

**Forudindstillinger — indstil alle udgangstyper på én gang:**

| Adresse | Forudindstillingstilstand |
|---|---|
| 1 | Dobbelt puls (standard) |
| 2 | Dobbelt stabil |
| 3 | Enkelt puls |
| 4 | Enkelt stabil |
| 5 | Dobbelt puls med Electrofrog-tilstand |

**Særlige muligheder:**

| Adresse | Indstilling |
|---|---|
| 20 | Deaktiver unikke udgangsadresser (standard) |
| 21 | Aktiver unikke udgangsadresser |
| 30 | Deaktiver DCC EXT-kommandounderstøttelse (standard) |
| 31 | Aktiver DCC EXT-pulslængdeunderstøttelse |
| 40 | Deaktiver lokomotivfunktionsstyring (standard) |
| 41 | Aktiver lokomotivfunktioner (F1–F16, 1 adresse) |
| 42 | Aktiver lokomotivfunktioner (F1–F4, 2+ adresser) |
| 996 / 1000 | Deaktiver Roco 4-adresse-forskydning (standard) |
| 997 / 1001 | Aktiver Roco 4-adresse-forskydning |

---

## 📟 Lokomotivfunktionsstyring forklaret

Du kan styre dekoderen ved hjælp af lokomotivfunktionsknapper (F1–F16) i stedet for DCC-tilbehørskommandoer.

**Fordele:**
- Virker med styrenheder som Roco Lokmaus 2
- Meget hurtig skift — ideel til hurtig anlægsstyring

**Tilstande:**
- **F1–F16-tilstand:** bruger 1 lokomotivadresse
- **F1–F4-tilstand:** bruger 2 eller flere lokomotivadresser (nyttigt til styrenheder, der kun understøtter F1–F4)

Den anvendte lokomotivadresse svarer til DCC-adressen tildelt til udgang 1.

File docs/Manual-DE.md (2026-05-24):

> 🌐 &nbsp; [🇬🇧 EN](Manual-EN.md) &nbsp;|&nbsp; 🇩🇪 DE &nbsp;|&nbsp; [🇫🇷 FR](Manual-FR.md) &nbsp;|&nbsp; [🇳🇱 NL](Manual-NL.md) &nbsp;|&nbsp; [🇪🇸 ES](Manual-ES.md) &nbsp;|&nbsp; [🇮🇹 IT](Manual-IT.md) &nbsp;|&nbsp; [🇵🇱 PL](Manual-PL.md) &nbsp;|&nbsp; [🇨🇿 CS](Manual-CS.md) &nbsp;|&nbsp; [🇩🇰 DA](Manual-DA.md) &nbsp;|&nbsp; [🇳🇴 NO](Manual-NO.md) &nbsp;|&nbsp; [🇸🇪 SV](Manual-SV.md) &nbsp;|&nbsp; [🇭🇺 HU](Manual-HU.md) &nbsp;|&nbsp; [🇵🇹 PT](Manual-PT.md)

# OS-Solenoid-Decoder

## 📘 Einführung

Der OS-Solenoid-Decoder ist ein einfacher, leistungsstarker DCC-Zubehördecoder zum Schalten von:

- Weichen (Weichenmotoren)
- Relais
- Entkupplern
- Allen anderen magnetartikelgetriebenen Geräten

Er kann Lasten von bis zu 5 A bewältigen und unterstützt nahezu jeden Typ von Weichenmotor.
Er kann auch in Kombination mit OS-Relais zur Herzstück-Polarisierung für Electrofrog- und Unifrog-Weichen verwendet werden.

Dieser Decoder wurde so konzipiert, dass er:

- **Einfach zu verkabeln** — steckbare Schraubklemmen erleichtern die Vorverdrahtung und ermöglichen ein schnelles Entfernen oder Ersetzen
- **Einfach zu konfigurieren** — verwendet ausschließlich Standard-DCC-Zubehörbefehle; kein Computer, kein CV, kein POM
- **Modular** — optionale Relais- und Transistor-Erweiterungsplatinen
- **Robust** — eingebauter Überlastschutz

ist. Ob beim Aufbau einer großen Anlage oder einfach, wenn etwas problemlos funktionieren soll: Dieser Decoder wurde gemacht, um die Aufgabe zu erledigen.

---

## Inhaltsverzeichnis

- [Merkmale](#-merkmale)
- [Anschließen des Decoders](#-anschließen-des-decoders)
- [Stromversorgung](#-stromversorgung)
- [Magnetartikelausgänge](#-magnetartikelausgänge)
- [Relaiserweiterung – Unifrog-Polarisierung](#-relaiserweiterung--unifrog-polarisierung)
- [Relaiserweiterung – Electrofrog-Polarisierung](#-relaiserweiterung--electrofrog-polarisierung)
- [Relaiserweiterung – Offener Kontakt (Universal)](#️-relaiserweiterung--offener-kontakt-universal)
- [Entkuppler und andere induktive Lasten](#-entkuppler-und-andere-induktive-lasten)
- [Konfigurieren des OS-Solenoid-Decoders](#️-konfigurieren-des-os-solenoid-decoders)
- [LED-Verhalten im Betriebsmodus](#-led-verhalten-im-betriebsmodus)
- [Aufrufen des Konfigurationsmodus](#-aufrufen-des-konfigurationsmodus)
- [Bevor du beginnst](#-bevor-du-beginnst)
- [Menüübersicht](#-menüübersicht)
- [Menü 1: DCC-Adresszuweisung](#-menü-1-dcc-adresszuweisung)
- [Menü 2: Ausgangstyp-Auswahl](#-menü-2-ausgangstyp-auswahl)
- [Menü 3: Impulszeitkonfiguration](#-menü-3-impulszeitkonfiguration)
- [Menü 4: PWM-Tastverhältnis](#-menü-4-pwm-tastverhältnis)
- [Menü 5: Globale Einstellungen & Voreinstellungen](#-menü-5-globale-einstellungen--voreinstellungen)
- [Lokfunktionssteuerung erklärt](#-lokfunktionssteuerung-erklärt)

---

## 🔧 Merkmale

- **Bis zu 5 A Gesamtausgangsstrom** — treibt schwere Magnetartikel, Relais oder Weichenmotoren ohne externe Booster an
- **Steckbare Schraubklemmen** — erleichtern die Vorverdrahtung und ermöglichen ein schnelles Entfernen oder Ersetzen des Decoders
- **Mehrere Ausgangsmodi:**
  - Doppelimpuls (Standard)
  - Einzelimpuls
  - Doppeldauerbetrieb
  - Einzeldauerbetrieb
  - Doppelimpuls mit Electrofrog-Relais
- **Jeweils ein Ausgang** — der Decoder schaltet jeweils ein Ausgangs paar, um Überlast zu verhindern
- **Optionale CDU-Modul-Unterstützung** — reduziert den Stromverbrauch und verlängert die Lebensdauer des Weichenmotors
- **Überlasterkennung und -schutz** — Ausgänge werden automatisch deaktiviert, wenn eine Überlast erkannt wird
- **Konfiguration ausschließlich über DCC-Befehle** — keine Programmiersoftware oder Hardware erforderlich
- **Vordefinierte Konfigurationsvoreinstellungen** — alle Ausgänge mit einem einzigen DCC-Befehl schnell auf Impuls-, Dauer- oder Electrofrog-Modus umschalten
- **Lokfunktionssteuerung** (F1–F16) — für schnelles Schalten über Fahrgeräte wie Roco Lokmaus oder Multimaus
- **Roco-Adress-Offset-Unterstützung** — eingebaute Unterstützung für den Roco 4-Adress-Offset
- **Erweiterbar mit Relais- und Transistorplatinen:**
  - Doppelrelaismodul für Electrofrog-Weichen-Polarisierung
  - Einzelnes bistabiles Relais für Unifrog-Polaritätsumschaltung
  - Offene-Kontakt-Relaismodule für allgemeine DCC-Relaissteuerung
  - Transistortreibermodul für 2-Draht-Weichenmotoren

---

## 🔌 Anschließen des Decoders

Der OS-Solenoid-Decoder folgt einem klaren und einheitlichen Verdrahtungsschema. Die Stromversorgung wird oben angeschlossen, die Ausgänge befinden sich auf beiden Seiten.

---

## 🔋 Stromversorgung

- Entweder DCC-Gleisspannung oder eine DC-Stromversorgung (max. 19 V) an den Decoder anschließen.
- Sowohl das DCC-Signal als auch die Stromleitungen werden von der oberen Seite des Decoders angeschlossen.
- ⚠️ Keine Wechselspannung verwenden — dies beschädigt den Decoder.

---

## ⚡ Magnetartikelausgänge

Der Decoder stellt 8 doppelte Ausgangsblöcke bereit, die für klassische Doppelspulen-Weichenmotoren ausgelegt sind.

Jeder Ausgangsblock hat:

- Zwei äußere Schraubklemmen — für die linke und rechte Spule (A und B)
- Eine mittlere Klemme — für den Gemeinsamdraht (COM), der zwischen beiden Spulen geteilt wird

Dieses Layout ermöglicht:

- Den Antrieb von bis zu 8 Doppelspulen-Weichenmotoren (z. B. PECO, Fleischmann, Märklin, Roco, Piko, Hornby)
- Oder den direkten Anschluss von 3-Draht-Weichenmotoren wie dem MTB MP-1

Ausgänge sind in Paaren mit klarer A-, COM- und B-Beschriftung gruppiert.

Magnetartikeldecoder mit 8 angeschlossenen Doppelspulen-Weichenmotoren

Obwohl der Decoder nicht für die Signalsteuerung konzipiert ist, kann er einfache Zweibegriff-Signale über dieselben Ausgänge ansteuern.

Verdrahtungsbeispiel für Zweibegriff-Signal

---

## 🔌 Relaiserweiterung – Unifrog-Polarisierung

Diese Erweiterung versorgt das Herzstück von Unifrog-Weichen automatisch über selbsthaltende Relais.

- Die Relaisplatine besteht aus vier kleinen Relaiseinheiten, die bei Bedarf auseinandergebrochen werden können, wenn weniger als vier benötigt werden.

Bistabile Relaiserweiterungsplatine

- Die Relais werden durch dasselbe Signal gerastet, das den Weichenmotor auslöst — keine zusätzliche Konfiguration erforderlich.
- Jede Relaiseinheit schaltet die Herzstück-Polarität entsprechend der Weichenrichtung.

Mit einem Relais pro Weiche bewältigt diese Erweiterung bis zu 8 Unifrog-Herzstücke mit zwei Platinen.

An Decoder montierte Relaiserweiterung für Unifrog-Verdrahtung

- Die Relaisplatine wird direkt in den Erweiterungsanschluss des Decoders eingesteckt, kann aber auch entfernt in der Nähe der Weiche montiert werden.

Beispiel für entfernt montierte Relaiserweiterung

Dieses Relaismodul ist auch mit anderen Magnetartikeldecoder kompatibel.

---

## ⚡ Relaiserweiterung – Electrofrog-Polarisierung

Electrofrog-Weichen benötigen zwei Relaisschalter pro Weiche:

1. Eines, um das Herzstück vor dem Schalten des Weichenmotors zu trennen
2. Eines, um es anschließend mit der richtigen Polarität wieder anzuschließen

Diese Erweiterung behandelt diese Sequenz automatisch. Sie besteht aus vier dauerhaft verbundenen Doppelrelaismodulen.

- Sie wird in die linke Seite des Decoders eingesteckt (für Electrofrog-Nutzung gekennzeichnet).
- Jedes Relaispaar ist mit einem Magnetartikelausgang verbunden: Ausgang 1 → Relaispaar 1, Ausgang 2 → Relaispaar 2, usw.
- Diese Module können nicht getrennt werden, da sie Gleisstrom und interne Logik teilen.

Der Decoder verfügt über einen speziellen Voreinstellungsmodus, der die Electrofrog-Schaltsequenz aktiviert.
Falls die Herzstück-Polarität nach der Installation falsch ist, die Jumper auf dem Relaismodul umstecken, um sie zu korrigieren — kein Umprogrammieren erforderlich.

---

## ⚙️ Relaiserweiterung – Offener Kontakt (Universal)

Zum Schalten externer Geräte (Beleuchtung, Signale, Logikschaltungen) über einfache Relaiskontakte:

- Jede Einheit bietet ein Wechselrelais (NO/NC), steuerbar über DCC.
- Bis zu 16 individuell adressierbare Relaiskontakte bei vollständiger Bestückung.
- Die Module werden direkt in den Decoder eingesteckt oder können über Kabel entfernt verwendet werden.
- Erhältlich in einer Durchsteckmontage-DIY-Version und einer kompakten SMD-Version.

Wie die Unifrog-Relaisplatinen können diese Module auseinandergebrochen und mit anderen DCC-Magnetartikeldecoder wiederverwendet werden.

Universalrelaismodule am Decoder montiert

Universalrelaismodul-Detail

Die Universalrelais-Erweiterung kann Electrofrog-Weichen auch mit etwas mehr Verdrahtungsaufwand polarisieren:

- Die NO-Kontakte (Normalerweise offen) verwenden
- Beide COM-Kontakte zusammenführen und mit dem Herzstück verbinden
- Die NO-Kontakte mit den Gleisstromschienen verbinden

Electrofrog-Verdrahtung mit Universalrelaismodulen

Falls ein Herzstück mit falscher Polarität endet, die beiden Gleisstromanschlüsse tauschen (wie für Herzstück 4 im obigen Diagramm gezeigt).

---

## 🧲 Entkuppler und andere induktive Lasten

Der OS-Solenoid-Decoder kann neben Weichenmotoren auch Entkuppler, Elektromagnete und andere induktive Lasten ansteuern.

- **Einzelimpuls-Modus** (empfohlen) — sendet einen kurzen Stromstoß, ideal für federgespannte oder zeitkritische Spulen
- **Einzeldauerbetrieb-Modus** — hält den Ausgang kontinuierlich ein, nützlich für monostabile Relais oder einfache EIN/AUS-Geräte

Entkuppler-Verdrahtungsbeispiel

⚠️ Entkuppler können überhitzen, wenn sie zu lange geschaltet werden — stets das Datenblatt des jeweiligen Gleisherstellers prüfen und Impulszeiten kurz halten.

---

## ⚙️ Konfigurieren des OS-Solenoid-Decoders

Standardmäßig arbeitet der Decoder im Normalbetrieb, wenn er mit Strom versorgt wird. Zwei LEDs geben visuelles Feedback über den aktuellen Zustand.

---

## 🔦 LED-Verhalten im Betriebsmodus

| LED-Muster | Modus |
|---|---|
| Beide LEDs blinken | Doppelimpuls (Standard) |
| Eine LED blinkt, eine AUS | Einzelimpuls |
| Beide LEDs EIN | Doppeldauerbetrieb |
| Eine LED EIN | Einzeldauerbetrieb |
| Eine LED EIN + andere LED blinkt | Electrofrog-Modus (Doppelimpuls + Frog-Relais) |

Wenn Ausgänge mit gemischten Typen konfiguriert sind, bleibt die linke LED EIN und die rechte LED blinkt einmal kontinuierlich, um den gemischten Konfigurationsmodus anzuzeigen.

---

## 🧰 Aufrufen des Konfigurationsmodus

So wird der Konfigurationsmodus aufgerufen:

1. Konfigurationstaste gedrückt halten. Die rechte LED beginnt zu blinken:
   - 1 Blinken = Menü 1
   - 2 Blinken = Menü 2
   - ... bis zu Menü 5
2. Taste loslassen, wenn die LED das gewünschte Menü erreicht.

Sobald in einem Menü:

- Die linke LED blinkt so oft wie die Menünummer (z. B. 3 Blinken = Menü 3).
- Die Taste erneut drücken, um das Menü zu verlassen, sofern der folgende Abschnitt nichts anderes angibt.

Konfigurationsmenü-Flussdiagramm

---

## 🧠 Bevor du beginnst

Falls gemischte Ausgangstypen geplant sind (z. B. Einzeldauerbetrieb für Relais neben Doppelimpuls für Weichenmotoren), die Ausgangszuweisungen zuerst auf Papier planen.

**Beispiel:** Wenn die Ausgänge 5–8 Einzeldauerbetrieb (für 8 Relais) und die Ausgänge 1–4 Doppeldauerbetrieb (für Weichenmotoren) sein sollen, müssen folgende Schritte durchgeführt werden:

1. Menü 2 verwenden, um die korrekten Ausgangstypen zuzuweisen
2. Dann Menü 1 verwenden, um DCC-Adressen sorgfältig zuzuweisen, da Einzelausgänge mehr Adressen verwenden

---

## 📖 Menüübersicht

| Menü | Funktion |
|---|---|
| 1 | DCC-Adresszuweisung |
| 2 | Ausgangstyp-Auswahl |
| 3 | Impulszeitkonfiguration |
| 4 | PWM-Tastverhältnis |
| 5 | Globale Einstellungen & Voreinstellungen |

---

## 🟠 Menü 1: DCC-Adresszuweisung

Dieses Menü verwenden, um jedem Ausgang DCC-Adressen zuzuweisen.

Regeln:
- Doppelmodi verwenden 1 Adresse
- Einzelmodi verwenden 2 Adressen (A und B separat)

Wenn Adresse 20 Ausgang 1 im Einzelmodus zugewiesen wird, belegt sie die Adressen 20 und 21. Ausgang 2 beginnt dann bei 22. Der Decoder behandelt diese Verschiebung automatisch.

Ausgänge auswählen:
- DCC-Zubehöradresse 1–8 senden, um einen Ausgang auszuwählen.
- Eine zweite Adresse senden, um diese dem Ausgang zuzuweisen.
- Adresse 9 als Selektor senden, um dieselbe Adresse auf alle Ausgänge gleichzeitig anzuwenden.

Im einzigartigen Adressierungsmodus kann jedem Ausgang eine benutzerdefinierte Adresse einschließlich wiederholter oder ausgelassener Nummern zugewiesen werden. Der Decoder kehrt unmittelbar nach der Zuweisung zum Betriebsmodus zurück, es sei denn, der einzigartige Modus ist aktiv — in diesem Fall die Konfigurationstaste drücken, um zu beenden.

---

## 🟡 Menü 2: Ausgangstyp-Auswahl

Jeder Ausgang kann auf einen der folgenden Typen eingestellt werden:

| Typ-ID | Modusbezeichnung |
|---|---|
| 1 | Doppelimpuls (Standard) |
| 2 | Doppeldauerbetrieb |
| 3 | Einzelimpuls |
| 4 | Einzeldauerbetrieb |
| 5 | Doppelimpuls mit Electrofrog-Relais-Unterstützung |

Im Electrofrog-Modus steuern die Ausgänge 1–4 die Relaispaare an den Ausgängen 8–5 in umgekehrter Reihenfolge (Ausgang 1 → Relais 8, Ausgang 2 → Relais 7, usw.).

Den zu konfigurierenden Ausgang durch Senden von DCC-Adresse 1–8 auswählen.

---

## 🔵 Menü 3: Impulszeitkonfiguration

Die Impulszeit für jeden Ausgang feinabstimmen.

**Einzelimpuls-Ausgänge:**
- Zeit wird in ganzen Sekunden eingestellt
- Adresse 10 = 10 Sekunden
- Bereich: 1–4096 Sekunden
- Standard: 5 s

**Doppelimpuls-Ausgänge:**
- Zeit wird in 10 ms-Schritten eingestellt
- Adresse 1 = 10 ms
- Maximum: 40,9 s (4096 × 10 ms)
- Standard: 50 ms

Adresse 9 senden, um dieselbe Zeit auf alle Ausgänge gleichzeitig anzuwenden.

---

## 🟣 Menü 4: PWM-Tastverhältnis

Verfügbar für Ausgänge, die im Dauerbetrieb (Einzel oder Doppel) konfiguriert sind.

PWM reduziert die durchschnittlich gelieferte Leistung — ideal für langsame Motoren wie den MTB MP-1.

- PWM-Frequenz: 50 Hz
- Adresse 10 = 100% Tastverhältnis (Standard; volle Leistung, kein PWM)

| Adresse | Tastverhältnis |
|---|---|
| 1 | 10% |
| 2 | 20% |
| ... | ... |
| 10 | 100% (Standard) |

Adresse 9 senden, um dasselbe Tastverhältnis auf alle Ausgänge anzuwenden.

---

## 🔘 Menü 5: Globale Einstellungen & Voreinstellungen

**Voreinstellungen — alle Ausgangstypen auf einmal einstellen:**

| Adresse | Voreinstellungsmodus |
|---|---|
| 1 | Doppelimpuls (Standard) |
| 2 | Doppeldauerbetrieb |
| 3 | Einzelimpuls |
| 4 | Einzeldauerbetrieb |
| 5 | Doppelimpuls mit Electrofrog-Modus |

**Spezielle Optionen:**

| Adresse | Einstellung |
|---|---|
| 20 | Einzigartige Ausgangsadressen deaktivieren (Standard) |
| 21 | Einzigartige Ausgangsadressen aktivieren |
| 30 | DCC EXT-Befehlsunterstützung deaktivieren (Standard) |
| 31 | DCC EXT-Impulslängen-Unterstützung aktivieren |
| 40 | Lokfunktionssteuerung deaktivieren (Standard) |
| 41 | Lokfunktionen aktivieren (F1–F16, 1 Adresse) |
| 42 | Lokfunktionen aktivieren (F1–F4, 2+ Adressen) |
| 996 / 1000 | Roco 4-Adress-Offset deaktivieren (Standard) |
| 997 / 1001 | Roco 4-Adress-Offset aktivieren |

---

## 📟 Lokfunktionssteuerung erklärt

Der Decoder kann über Lokfunktionstasten (F1–F16) anstelle von DCC-Zubehörbefehlen gesteuert werden.

**Vorteile:**
- Funktioniert mit Fahrgeräten wie der Roco Lokmaus 2
- Sehr schnelles Schalten — ideal für schnelle Anlagensteuerung

**Modi:**
- **F1–F16-Modus:** verwendet 1 Lokadresse
- **F1–F4-Modus:** verwendet 2 oder mehr Lokadressen (nützlich für Fahrgeräte, die nur F1–F4 unterstützen)

Die verwendete Lokadresse entspricht der DCC-Adresse, die Ausgang 1 zugewiesen ist.

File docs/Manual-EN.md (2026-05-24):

> 🌐 &nbsp; 🇬🇧 EN &nbsp;|&nbsp; [🇩🇪 DE](Manual-DE.md) &nbsp;|&nbsp; [🇫🇷 FR](Manual-FR.md) &nbsp;|&nbsp; [🇳🇱 NL](Manual-NL.md) &nbsp;|&nbsp; [🇪🇸 ES](Manual-ES.md) &nbsp;|&nbsp; [🇮🇹 IT](Manual-IT.md) &nbsp;|&nbsp; [🇵🇱 PL](Manual-PL.md) &nbsp;|&nbsp; [🇨🇿 CS](Manual-CS.md) &nbsp;|&nbsp; [🇩🇰 DA](Manual-DA.md) &nbsp;|&nbsp; [🇳🇴 NO](Manual-NO.md) &nbsp;|&nbsp; [🇸🇪 SV](Manual-SV.md) &nbsp;|&nbsp; [🇭🇺 HU](Manual-HU.md) &nbsp;|&nbsp; [🇵🇹 PT](Manual-PT.md)

# OS-Solenoid-Decoder

## 📘 Introduction

The OS-Solenoid-Decoder is a simple, powerful DCC accessory decoder for switching:

- Turnouts (point motors)
- Relays
- Uncouplers
- Any other solenoid-driven device

It can handle loads of up to 5 amps and supports almost any type of point motor.
It can also be used in combination with OS-relays to handle frog polarization for both electrofrog and unifrog turnouts.

This decoder is designed to be:

- **Easy to wire** — pluggable screw terminals make pre-wiring straightforward and allow quick removal or replacement
- **Easy to configure** — uses only standard DCC accessory commands; no computer, no CV, no POM
- **Modular** — optional relay and transistor expansion boards
- **Robust** — built-in overload protection

Whether you're building a large layout or just want something that works without hassle: this decoder is made to get the job done.

---

## Table of Contents

- [Features](#-features)
- [Connecting the Decoder](#-connecting-the-decoder)
- [Power Supply](#-power-supply)
- [Solenoid Outputs](#-solenoid-outputs)
- [Relay Extension – Unifrog Polarization](#-relay-extension--unifrog-polarization)
- [Relay Extension – Electrofrog Polarization](#-relay-extension--electrofrog-polarization)
- [Relay Extension – Open Contact (General Purpose)](#️-relay-extension--open-contact-general-purpose)
- [Decouplers and Other Inductive Loads](#-decouplers-and-other-inductive-loads)
- [Configuring the OS-Solenoid-Decoder](#️-configuring-the-os-solenoid-decoder)
- [LED Behavior in Operating Mode](#-led-behavior-in-operating-mode)
- [Entering Configuration Mode](#-entering-configuration-mode)
- [Before You Start](#-before-you-start)
- [Menu Overview](#-menu-overview)
- [Menu 1: DCC Address Assignment](#-menu-1-dcc-address-assignment)
- [Menu 2: Output Type Selection](#-menu-2-output-type-selection)
- [Menu 3: Pulse Time Configuration](#-menu-3-pulse-time-configuration)
- [Menu 4: PWM Duty Cycle](#-menu-4-pwm-duty-cycle)
- [Menu 5: Global Settings & Presets](#-menu-5-global-settings--presets)
- [Loco Function Control Explained](#-loco-function-control-explained)

---

## 🔧 Features

- **Up to 5 A total output current** — drives heavy-duty solenoids, relays or turnout motors without external boosters
- **Pluggable screw terminals** — makes pre-wiring easy and allows quick removal or replacement of the decoder
- **Multiple output modes:**
  - Double Pulse (default)
  - Single Pulse
  - Double Steady
  - Single Steady
  - Double Pulse with Electrofrog Relay
- **One output at a time** — the decoder switches one output pair at a time to prevent overload
- **Optional CDU module support** — reduces power consumption and extends turnout motor life
- **Overload detection and protection** — outputs are automatically disabled if an overload is detected
- **Configuration via DCC commands only** — no programming software or hardware required
- **Predefined configuration presets** — quickly switch all outputs to pulse, steady, or electrofrog mode with a single DCC command
- **Loco function control** (F1–F16) — for fast switching via throttles like the Roco Lokmaus or Multimaus
- **Roco address offset support** — built-in support for the Roco 4-address offset
- **Expandable with relay and transistor boards:**
  - Double relay module for electrofrog turnout polarization
  - Single latching relay for unifrog polarity switching
  - Open-contact relay modules for general-purpose DCC relay control
  - Transistor driver module for two-wire turnout motors

---

## 🔌 Connecting the Decoder

The OS-Solenoid-Decoder follows a clear and consistent wiring layout. Power is connected at the top, outputs are on both sides.

---

## 🔋 Power Supply

- Connect either DCC track voltage or a DC power supply (max. 19 V) to the decoder.
- Both the DCC signal and the power lines connect from the top side of the decoder.
- ⚠️ Do not use AC voltage — this will damage the decoder.

---

## ⚡ Solenoid Outputs

The decoder provides 8 dual output blocks, designed for classic twin-coil turnout motors.

Each output block has:

- Two outer screw terminals — for the left and right coil (A and B)
- One center terminal — for the common wire (COM), shared between the two coils

This layout lets you:

- Drive up to 8 twin-coil point motors (e.g. PECO, Fleischmann, Märklin, Roco, Piko, Hornby)
- Or connect 3-wire turnout motors like the MTB MP-1 directly

Outputs are grouped in pairs with clear A, COM, and B labeling.

Solenoid decoder with 8 twin-coil point motors connected

Although the decoder is not designed for signal control, it can drive simple two-aspect signals using the same outputs.

Two-aspect signal wiring example

---

## 🔌 Relay Extension – Unifrog Polarization

This extension automatically powers the frog of unifrog turnouts using self-latching relays.

- The relay board consists of four small relay units, which can be snapped apart if you need fewer than four.

Latching relay extension board

- The relays are latched by the same signal used to trigger the turnout motor — no extra configuration is needed.
- Each relay unit switches the frog polarity based on the direction of the turnout.

With one relay per turnout, this extension handles up to 8 unifrog frogs using two boards.

Relay extension fitted to decoder for unifrog wiring

- The relay board plugs directly into the decoder's expansion header, but can also be mounted remotely near the turnout.

Remote-mounted relay extension example

This relay module is also compatible with other solenoid decoders.

---

## ⚡ Relay Extension – Electrofrog Polarization

Electrofrog turnouts require two relay switches per turnout:

1. One to disconnect the frog before switching the point motor
2. One to reconnect it with the correct polarity afterwards

This extension handles that sequence automatically. It consists of four dual-relay modules, permanently linked.

- It plugs into the left side of the decoder (marked for electrofrog use).
- Each relay pair is linked to one solenoid output: output 1 → relay pair 1, output 2 → relay pair 2, etc.
- These modules cannot be separated, as they share track power and internal logic.

The decoder has a special preset mode that activates the electrofrog switching sequence.
If frog polarity is wrong after installation, flip the jumpers on the relay module to correct it — no reprogramming needed.

---

## ⚙️ Relay Extension – Open Contact (General Purpose)

For switching external devices (lights, signals, logic circuits) using plain relay contacts:

- Each unit provides a double-throw (NO/NC) relay, controllable via DCC.
- Up to 16 individually addressable relay contacts when fully populated.
- The modules plug directly into the decoder or can be used remotely with wires.
- Available in a through-hole DIY version and a compact SMD version.

Like the unifrog relay boards, these modules can be snapped apart and reused with other DCC solenoid decoders.

General-purpose relay modules fitted to the decoder

General-purpose relay module detail

The General Purpose relay extension can also polarize electrofrog turnouts with slightly more wiring:

- Use the NO (Normally Open) contacts
- Loop both COM contacts together and connect them to the frog
- Connect the NO contacts to the track power rails

Electrofrog wiring using General Purpose relay modules

If a frog ends up with the wrong polarity, swap the two track power lines (as shown for frog 4 in the diagram above).

---

## 🧲 Decouplers and Other Inductive Loads

The OS-Solenoid-Decoder can drive decouplers, electromagnets, and other inductive loads in addition to turnout motors.

- **Single Pulse mode** (recommended) — sends a short burst of current, ideal for spring-loaded or time-sensitive coils
- **Single Steady mode** — keeps the output continuously on, useful for monostable relays or simple ON/OFF devices

Decoupler wiring example

⚠️ Decouplers can overheat if switched for too long — always check the datasheet for your track brand and keep pulse times short.

---

## ⚙️ Configuring the OS-Solenoid-Decoder

By default the decoder operates in normal mode when powered. Two LEDs provide visual feedback about what's happening.

---

## 🔦 LED Behavior in Operating Mode

| LED Pattern | Mode |
|---|---|
| Both LEDs blinking | Double Pulse (default) |
| One LED blinking, one OFF | Single Pulse |
| Both LEDs ON | Double Steady |
| One LED ON | Single Steady |
| One LED ON + other LED blinking | Electrofrog Mode (double pulse + frog relay) |

When outputs are configured with mixed types, the left LED stays ON and the right LED blinks once continuously to indicate mixed-config mode.

---

## 🧰 Entering Configuration Mode

To enter configuration mode:

1. Hold the configuration button. The right LED starts blinking:
   - 1 blink = Menu 1
   - 2 blinks = Menu 2
   - ... up to Menu 5
2. Release the button when the LED reaches the menu you want.

Once in a menu:

- The left LED blinks the same number of times as the menu number (e.g. 3 blinks = Menu 3).
- Press the button again to exit the menu, unless the section below says otherwise.

Configuration menu flowchart

---

## 🧠 Before You Start

If you plan to use mixed output types (e.g. Single Steady for relays alongside Double Pulse for point motors), plan your output assignments on paper first.

**Example:** if outputs 5–8 should be Single Steady (for 8 relays) and outputs 1–4 should be Double Steady (for point motors), you must:

1. Use Menu 2 to assign the correct output types
2. Then use Menu 1 to assign DCC addresses carefully, because Single outputs use more addresses

---

## 📖 Menu Overview

| Menu | Function |
|---|---|
| 1 | DCC Address Assignment |
| 2 | Output Type Selection |
| 3 | Pulse Time Configuration |
| 4 | PWM Duty Cycle |
| 5 | Global Settings & Presets |

---

## 🟠 Menu 1: DCC Address Assignment

Use this menu to assign DCC addresses to each output.

Rules:
- Double modes use 1 address
- Single modes use 2 addresses (A and B separately)

If you assign address 20 to Output 1 in Single mode, it will occupy addresses 20 and 21. Output 2 will then start at 22. The decoder handles this shifting automatically.

Selecting outputs:
- Send DCC accessory address 1–8 to select an output.
- Send a second address to assign it to that output.
- Send address 9 as the selector to apply the same address to all outputs at once.

In unique addressing mode, you can give every output a custom address including repeated or skipped numbers. The decoder returns to operating mode immediately after assignment, unless unique mode is active — in that case press the config button to exit.

---

## 🟡 Menu 2: Output Type Selection

Each output can be set to one of the following types:

| Type ID | Mode Description |
|---|---|
| 1 | Double Pulse (default) |
| 2 | Double Steady |
| 3 | Single Pulse |
| 4 | Single Steady |
| 5 | Double Pulse with Electrofrog relay support |

In Electrofrog mode, outputs 1–4 control the relay pairs on outputs 8–5 in reversed order (output 1 → relay 8, output 2 → relay 7, etc.).

Select which output to configure by sending DCC address 1–8.

---

## 🔵 Menu 3: Pulse Time Configuration

Fine-tune the pulse time for each output.

**Single Pulse outputs:**
- Time is set in whole seconds
- Address 10 = 10 seconds
- Range: 1–4096 seconds
- Default: 5 s

**Double Pulse outputs:**
- Time is set in 10 ms steps
- Address 1 = 10 ms
- Maximum: 40.9 s (4096 × 10 ms)
- Default: 50 ms

Send address 9 to apply the same time to all outputs at once.

---

## 🟣 Menu 4: PWM Duty Cycle

Available for outputs configured in Steady mode (Single or Double).

PWM reduces the average power delivered — ideal for slow motors like the MTB MP-1.

- PWM frequency: 50 Hz
- Address 10 = 100% duty cycle (default; full power, no PWM)

| Address | Duty Cycle |
|---|---|
| 1 | 10% |
| 2 | 20% |
| ... | ... |
| 10 | 100% (default) |

Send address 9 to apply the same duty cycle to all outputs.

---

## 🔘 Menu 5: Global Settings & Presets

**Presets — set all output types at once:**

| Address | Preset Mode |
|---|---|
| 1 | Double Pulse (default) |
| 2 | Double Steady |
| 3 | Single Pulse |
| 4 | Single Steady |
| 5 | Double Pulse with Electrofrog mode |

**Special options:**

| Address | Setting |
|---|---|
| 20 | Disable unique output addresses (default) |
| 21 | Enable unique output addresses |
| 30 | Disable DCC EXT command support (default) |
| 31 | Enable DCC EXT pulse-length support |
| 40 | Disable loco function control (default) |
| 41 | Enable loco functions (F1–F16, 1 address) |
| 42 | Enable loco functions (F1–F4, 2+ addresses) |
| 996 / 1000 | Disable Roco 4-address offset (default) |
| 997 / 1001 | Enable Roco 4-address offset |

---

## 📟 Loco Function Control Explained

You can control the decoder using locomotive function keys (F1–F16) instead of DCC accessory commands.

**Benefits:**
- Works with throttles like the Roco Lokmaus 2
- Very fast switching — ideal for quick layout control

**Modes:**
- **F1–F16 mode:** uses 1 loco address
- **F1–F4 mode:** uses 2 or more loco addresses (useful for throttles that only support F1–F4)

The loco address used matches the DCC address assigned to Output 1.

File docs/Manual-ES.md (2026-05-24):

> 🌐 &nbsp; [🇬🇧 EN](Manual-EN.md) &nbsp;|&nbsp; [🇩🇪 DE](Manual-DE.md) &nbsp;|&nbsp; [🇫🇷 FR](Manual-FR.md) &nbsp;|&nbsp; [🇳🇱 NL](Manual-NL.md) &nbsp;|&nbsp; 🇪🇸 ES &nbsp;|&nbsp; [🇮🇹 IT](Manual-IT.md) &nbsp;|&nbsp; [🇵🇱 PL](Manual-PL.md) &nbsp;|&nbsp; [🇨🇿 CS](Manual-CS.md) &nbsp;|&nbsp; [🇩🇰 DA](Manual-DA.md) &nbsp;|&nbsp; [🇳🇴 NO](Manual-NO.md) &nbsp;|&nbsp; [🇸🇪 SV](Manual-SV.md) &nbsp;|&nbsp; [🇭🇺 HU](Manual-HU.md) &nbsp;|&nbsp; [🇵🇹 PT](Manual-PT.md)

# OS-Solenoid-Decoder

## 📘 Introducción

El OS-Solenoid-Decoder es un decodificador de accesorios DCC sencillo y potente para conmutar:

- Agujas (motores de aguja)
- Relés
- Desenganchadores
- Cualquier otro dispositivo accionado por solenoide

Puede gestionar cargas de hasta 5 A y es compatible con casi cualquier tipo de motor de aguja.
También puede usarse en combinación con OS-relays para gestionar la polarización de frog tanto en agujas electrofrog como unifrog.

Este decodificador está diseñado para ser:

- **Fácil de cablear** — los bornes de tornillo enchufables facilitan el precableado y permiten la extracción o sustitución rápida
- **Fácil de configurar** — utiliza únicamente comandos de accesorio DCC estándar; sin ordenador, sin CV, sin POM
- **Modular** — placas de expansión de relé y transistor opcionales
- **Robusto** — protección integrada contra sobrecargas

Tanto si está construyendo una gran maqueta como si simplemente quiere algo que funcione sin complicaciones: este decodificador está hecho para cumplir el trabajo.

---

## Tabla de Contenidos

- [Características](#-características)
- [Conexión del Decodificador](#-conexión-del-decodificador)
- [Alimentación](#-alimentación)
- [Salidas de Solenoide](#-salidas-de-solenoide)
- [Extensión de Relé – Polarización Unifrog](#-extensión-de-relé--polarización-unifrog)
- [Extensión de Relé – Polarización Electrofrog](#-extensión-de-relé--polarización-electrofrog)
- [Extensión de Relé – Contacto Abierto (Uso General)](#️-extensión-de-relé--contacto-abierto-uso-general)
- [Desenganchadores y Otras Cargas Inductivas](#-desenganchadores-y-otras-cargas-inductivas)
- [Configuración del OS-Solenoid-Decoder](#️-configuración-del-os-solenoid-decoder)
- [Comportamiento del LED en Modo de Funcionamiento](#-comportamiento-del-led-en-modo-de-funcionamiento)
- [Acceso al Modo de Configuración](#-acceso-al-modo-de-configuración)
- [Antes de Empezar](#-antes-de-empezar)
- [Descripción General del Menú](#-descripción-general-del-menú)
- [Menú 1: Asignación de Dirección DCC](#-menú-1-asignación-de-dirección-dcc)
- [Menú 2: Selección del Tipo de Salida](#-menú-2-selección-del-tipo-de-salida)
- [Menú 3: Configuración del Tiempo de Impulso](#-menú-3-configuración-del-tiempo-de-impulso)
- [Menú 4: Ciclo de Trabajo PWM](#-menú-4-ciclo-de-trabajo-pwm)
- [Menú 5: Ajustes Globales y Preajustes](#-menú-5-ajustes-globales-y-preajustes)
- [Explicación del Control por Función de Locomotora](#-explicación-del-control-por-función-de-locomotora)

---

## 🔧 Características

- **Hasta 5 A de corriente total de salida** — acciona solenoides, relés o motores de aguja de alto rendimiento sin amplificadores externos
- **Bornes de tornillo enchufables** — facilitan el precableado y permiten la extracción o sustitución rápida del decodificador
- **Múltiples modos de salida:**
  - Impulso doble (predeterminado)
  - Impulso simple
  - Continuo doble
  - Continuo simple
  - Impulso doble con relé Electrofrog
- **Una salida a la vez** — el decodificador conmuta un par de salidas a la vez para evitar sobrecargas
- **Compatible con módulo CDU opcional** — reduce el consumo de energía y prolonga la vida del motor de aguja
- **Detección y protección contra sobrecargas** — las salidas se deshabilitan automáticamente si se detecta una sobrecarga
- **Configuración solo mediante comandos DCC** — no se requiere software ni hardware de programación
- **Preajustes de configuración predefinidos** — cambie todas las salidas a modo impulso, continuo o electrofrog con un único comando DCC
- **Control por función de locomotora** (F1–F16) — para conmutación rápida mediante mandos como el Roco Lokmaus o el Multimaus
- **Compatible con el desplazamiento de dirección de Roco** — soporte integrado para el desplazamiento de 4 direcciones de Roco
- **Ampliable con placas de relé y transistor:**
  - Módulo de doble relé para polarización de agujas electrofrog
  - Relé enclavado simple para conmutación de polaridad unifrog
  - Módulos de relé de contacto abierto para control de relé DCC de uso general
  - Módulo de controlador de transistores para motores de aguja de dos hilos

---

## 🔌 Conexión del Decodificador

El OS-Solenoid-Decoder sigue un esquema de cableado claro y coherente. La alimentación se conecta en la parte superior, las salidas están en ambos lados.

---

## 🔋 Alimentación

- Conecte la tensión de vía DCC o una fuente de alimentación DC (máx. 19 V) al decodificador.
- Tanto la señal DCC como los cables de alimentación se conectan por la parte superior del decodificador.
- ⚠️ No use tensión AC — esto dañará el decodificador.

---

## ⚡ Salidas de Solenoide

El decodificador proporciona 8 bloques de salida dual, diseñados para motores de aguja clásicos de doble bobina.

Cada bloque de salida tiene:

- Dos bornes de tornillo exteriores — para la bobina izquierda y derecha (A y B)
- Un borne central — para el cable común (COM), compartido entre las dos bobinas

Este diseño permite:

- Accionar hasta 8 motores de aguja de doble bobina (p. ej. PECO, Fleischmann, Märklin, Roco, Piko, Hornby)
- O conectar directamente motores de aguja de 3 hilos como el MTB MP-1

Las salidas se agrupan en pares con etiquetado claro de A, COM y B.

Decodificador de solenoide con 8 motores de aguja de doble bobina conectados

Aunque el decodificador no está diseñado para el control de señales, puede accionar señales simples de dos aspectos usando las mismas salidas.

Ejemplo de cableado de señal de dos aspectos

---

## 🔌 Extensión de Relé – Polarización Unifrog

Esta extensión alimenta automáticamente el frog de agujas unifrog mediante relés de autoenclavamiento.

- La placa de relé consta de cuatro pequeñas unidades de relé que pueden separarse si se necesitan menos de cuatro.

Placa de extensión de relé enclavado

- Los relés se enclavana través de la misma señal utilizada para accionar el motor de aguja — no se necesita configuración adicional.
- Cada unidad de relé conmuta la polaridad del frog según la dirección de la aguja.

Con un relé por aguja, esta extensión gestiona hasta 8 frogs unifrog usando dos placas.

Extensión de relé montada en el decodificador para cableado unifrog

- La placa de relé se enchufa directamente en el cabezal de expansión del decodificador, pero también puede montarse de forma remota cerca de la aguja.

Ejemplo de extensión de relé montada de forma remota

Este módulo de relé también es compatible con otros decodificadores de solenoide.

---

## ⚡ Extensión de Relé – Polarización Electrofrog

Las agujas electrofrog requieren dos conmutaciones de relé por aguja:

1. Una para desconectar el frog antes de conmutar el motor de aguja
2. Otra para reconectarlo con la polaridad correcta

Esta extensión gestiona esa secuencia automáticamente. Consta de cuatro módulos de doble relé, permanentemente vinculados.

- Se enchufa en el lado izquierdo del decodificador (marcado para uso con electrofrog).
- Cada par de relés está vinculado a una salida de solenoide: salida 1 → par de relés 1, salida 2 → par de relés 2, etc.
- Estos módulos no pueden separarse, ya que comparten la alimentación de vía y la lógica interna.

El decodificador tiene un modo de preajuste especial que activa la secuencia de conmutación electrofrog.
Si la polaridad del frog es incorrecta tras la instalación, invierta los puentes del módulo de relé para corregirla — no es necesario reprogramar.

---

## ⚙️ Extensión de Relé – Contacto Abierto (Uso General)

Para conmutar dispositivos externos (luces, señales, circuitos lógicos) mediante contactos de relé simples:

- Cada unidad proporciona un relé de doble conmutación (NO/NC), controlable mediante DCC.
- Hasta 16 contactos de relé individualmente direccionables cuando está completamente instalado.
- Los módulos se enchufan directamente en el decodificador o pueden usarse de forma remota con cables.
- Disponible en una versión DIY de agujeros pasantes y una versión SMD compacta.

Al igual que las placas de relé unifrog, estos módulos pueden separarse y reutilizarse con otros decodificadores de solenoide DCC.

Módulos de relé de uso general montados en el decodificador

Detalle del módulo de relé de uso general

La extensión de relé de uso general también puede polarizar agujas electrofrog con un cableado ligeramente más complejo:

- Use los contactos NO (Normalmente Abiertos)
- Una ambos contactos COM y conéctelos al frog
- Conecte los contactos NO a los carriles de alimentación de la vía

Cableado electrofrog usando módulos de relé de uso general

Si un frog resulta con la polaridad incorrecta, intercambie las dos líneas de alimentación de vía (como se muestra para el frog 4 en el diagrama anterior).

---

## 🧲 Desenganchadores y Otras Cargas Inductivas

El OS-Solenoid-Decoder puede accionar desenganchadores, electroimanes y otras cargas inductivas además de motores de aguja.

- **Modo de Impulso Simple** (recomendado) — envía una ráfaga corta de corriente, ideal para bobinas con resorte o sensibles al tiempo
- **Modo Continuo Simple** — mantiene la salida encendida de forma continua, útil para relés monoestables o dispositivos simples de ON/OFF

Ejemplo de cableado de desenganchador

⚠️ Los desenganchadores pueden sobrecalentarse si se conmutan durante demasiado tiempo — compruebe siempre las especificaciones de su marca de vía y mantenga los tiempos de impulso cortos.

---

## ⚙️ Configuración del OS-Solenoid-Decoder

Por defecto, el decodificador funciona en modo normal al encenderse. Dos LED proporcionan información visual sobre lo que está ocurriendo.

---

## 🔦 Comportamiento del LED en Modo de Funcionamiento

| Patrón de LED | Modo |
|---|---|
| Ambos LED parpadeando | Impulso doble (predeterminado) |
| Un LED parpadeando, uno APAGADO | Impulso simple |
| Ambos LED encendidos | Continuo doble |
| Un LED encendido | Continuo simple |
| Un LED encendido + otro LED parpadeando | Modo Electrofrog (impulso doble + relé de frog) |

Cuando las salidas están configuradas con tipos mixtos, el LED izquierdo permanece encendido y el LED derecho parpadea una vez de forma continua para indicar el modo de configuración mixta.

---

## 🧰 Acceso al Modo de Configuración

Para entrar en el modo de configuración:

1. Mantenga pulsado el botón de configuración. El LED derecho empieza a parpadear:
   - 1 parpadeo = Menú 1
   - 2 parpadeos = Menú 2
   - ... hasta el Menú 5
2. Suelte el botón cuando el LED llegue al menú deseado.

Una vez en un menú:

- El LED izquierdo parpadea el mismo número de veces que el número de menú (p. ej. 3 parpadeos = Menú 3).
- Pulse el botón de nuevo para salir del menú, salvo que la sección correspondiente indique otra cosa.

Diagrama de flujo del menú de configuración

---

## 🧠 Antes de Empezar

Si planea usar tipos de salida mixtos (p. ej. Continuo Simple para relés junto con Impulso Doble para motores de aguja), planifique previamente las asignaciones de salida en papel.

**Ejemplo:** si las salidas 5–8 deben ser Continuo Simple (para 8 relés) y las salidas 1–4 deben ser Continuo Doble (para motores de aguja), debe:

1. Usar el Menú 2 para asignar los tipos de salida correctos
2. Luego usar el Menú 1 para asignar las direcciones DCC con cuidado, porque las salidas individuales usan más direcciones

---

## 📖 Descripción General del Menú

| Menú | Función |
|---|---|
| 1 | Asignación de Dirección DCC |
| 2 | Selección del Tipo de Salida |
| 3 | Configuración del Tiempo de Impulso |
| 4 | Ciclo de Trabajo PWM |
| 5 | Ajustes Globales y Preajustes |

---

## 🟠 Menú 1: Asignación de Dirección DCC

Use este menú para asignar direcciones DCC a cada salida.

Reglas:
- Los modos dobles usan 1 dirección
- Los modos individuales usan 2 direcciones (A y B por separado)

Si asigna la dirección 20 a la Salida 1 en modo Individual, ocupará las direcciones 20 y 21. La Salida 2 comenzará entonces en la 22. El decodificador gestiona este desplazamiento automáticamente.

Selección de salidas:
- Envíe la dirección de accesorio DCC 1–8 para seleccionar una salida.
- Envíe una segunda dirección para asignarla a esa salida.
- Envíe la dirección 9 como selector para aplicar la misma dirección a todas las salidas a la vez.

En el modo de direccionamiento único, puede asignar a cada salida una dirección personalizada incluyendo números repetidos u omitidos. El decodificador vuelve al modo de funcionamiento inmediatamente tras la asignación, a menos que el modo único esté activo — en ese caso pulse el botón de configuración para salir.

---

## 🟡 Menú 2: Selección del Tipo de Salida

Cada salida puede configurarse en uno de los siguientes tipos:

| ID de tipo | Descripción del modo |
|---|---|
| 1 | Impulso doble (predeterminado) |
| 2 | Continuo doble |
| 3 | Impulso simple |
| 4 | Continuo simple |
| 5 | Impulso doble con soporte de relé Electrofrog |

En el modo Electrofrog, las salidas 1–4 controlan los pares de relés en las salidas 8–5 en orden inverso (salida 1 → relé 8, salida 2 → relé 7, etc.).

Seleccione qué salida configurar enviando la dirección DCC 1–8.

---

## 🔵 Menú 3: Configuración del Tiempo de Impulso

Ajuste con precisión el tiempo de impulso de cada salida.

**Salidas de Impulso Simple:**
- El tiempo se establece en segundos enteros
- Dirección 10 = 10 segundos
- Rango: 1–4096 segundos
- Predeterminado: 5 s

**Salidas de Impulso Doble:**
- El tiempo se establece en pasos de 10 ms
- Dirección 1 = 10 ms
- Máximo: 40,9 s (4096 × 10 ms)
- Predeterminado: 50 ms

Envíe la dirección 9 para aplicar el mismo tiempo a todas las salidas a la vez.

---

## 🟣 Menú 4: Ciclo de Trabajo PWM

Disponible para salidas configuradas en modo Continuo (simple o doble).

PWM reduce la potencia media entregada — ideal para motores lentos como el MTB MP-1.

- Frecuencia PWM: 50 Hz
- Dirección 10 = 100% de ciclo de trabajo (predeterminado; potencia máxima, sin PWM)

| Dirección | Ciclo de trabajo |
|---|---|
| 1 | 10% |
| 2 | 20% |
| ... | ... |
| 10 | 100% (predeterminado) |

Envíe la dirección 9 para aplicar el mismo ciclo de trabajo a todas las salidas.

---

## 🔘 Menú 5: Ajustes Globales y Preajustes

**Preajustes — establezca todos los tipos de salida a la vez:**

| Dirección | Modo de preajuste |
|---|---|
| 1 | Impulso doble (predeterminado) |
| 2 | Continuo doble |
| 3 | Impulso simple |
| 4 | Continuo simple |
| 5 | Impulso doble con modo Electrofrog |

**Opciones especiales:**

| Dirección | Ajuste |
|---|---|
| 20 | Deshabilitar direcciones de salida únicas (predeterminado) |
| 21 | Habilitar direcciones de salida únicas |
| 30 | Deshabilitar soporte de comandos DCC EXT (predeterminado) |
| 31 | Habilitar soporte de longitud de impulso DCC EXT |
| 40 | Deshabilitar control por función de locomotora (predeterminado) |
| 41 | Habilitar funciones de locomotora (F1–F16, 1 dirección) |
| 42 | Habilitar funciones de locomotora (F1–F4, 2+ direcciones) |
| 996 / 1000 | Deshabilitar desplazamiento de 4 direcciones de Roco (predeterminado) |
| 997 / 1001 | Habilitar desplazamiento de 4 direcciones de Roco |

---

## 📟 Explicación del Control por Función de Locomotora

Puede controlar el decodificador usando las teclas de función de locomotora (F1–F16) en lugar de comandos de accesorio DCC.

**Ventajas:**
- Funciona con mandos como el Roco Lokmaus 2
- Conmutación muy rápida — ideal para un control ágil de la maqueta

**Modos:**
- **Modo F1–F16:** usa 1 dirección de locomotora
- **Modo F1–F4:** usa 2 o más direcciones de locomotora (útil para mandos que solo admiten F1–F4)

La dirección de locomotora usada coincide con la dirección DCC asignada a la Salida 1.

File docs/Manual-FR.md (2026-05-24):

> 🌐 &nbsp; [🇬🇧 EN](Manual-EN.md) &nbsp;|&nbsp; [🇩🇪 DE](Manual-DE.md) &nbsp;|&nbsp; 🇫🇷 FR &nbsp;|&nbsp; [🇳🇱 NL](Manual-NL.md) &nbsp;|&nbsp; [🇪🇸 ES](Manual-ES.md) &nbsp;|&nbsp; [🇮🇹 IT](Manual-IT.md) &nbsp;|&nbsp; [🇵🇱 PL](Manual-PL.md) &nbsp;|&nbsp; [🇨🇿 CS](Manual-CS.md) &nbsp;|&nbsp; [🇩🇰 DA](Manual-DA.md) &nbsp;|&nbsp; [🇳🇴 NO](Manual-NO.md) &nbsp;|&nbsp; [🇸🇪 SV](Manual-SV.md) &nbsp;|&nbsp; [🇭🇺 HU](Manual-HU.md) &nbsp;|&nbsp; [🇵🇹 PT](Manual-PT.md)

# OS-Solenoid-Decoder

## 📘 Introduction

Le OS-Solenoid-Decoder est un décodeur DCC accessoire simple et puissant pour la commutation de :

- Aiguilles (moteurs d'aiguille)
- Relais
- Dételeurs
- Tout autre dispositif à entraînement solénoïde

Il peut supporter des charges allant jusqu'à 5 A et prend en charge presque tous les types de moteurs d'aiguille.
Il peut également être utilisé en combinaison avec des OS-relays pour gérer la polarisation du cœur d'aiguille pour les aiguilles Electrofrog et Unifrog.

Ce décodeur est conçu pour être :

- **Facile à câbler** — les borniers à vis enfichables facilitent le précâblage et permettent un retrait ou un remplacement rapide
- **Facile à configurer** — utilise uniquement des commandes DCC accessoire standard ; aucun ordinateur, aucun CV, aucun POM
- **Modulaire** — cartes d'extension relais et transistors optionnelles
- **Robuste** — protection intégrée contre les surcharges

Que vous construisiez un grand réseau ou que vous vouliez simplement quelque chose qui fonctionne sans complications : ce décodeur est fait pour accomplir la tâche.

---

## Table des matières

- [Caractéristiques](#-caractéristiques)
- [Connexion du décodeur](#-connexion-du-décodeur)
- [Alimentation électrique](#-alimentation-électrique)
- [Sorties solénoïde](#-sorties-solénoïde)
- [Extension relais – Polarisation Unifrog](#-extension-relais--polarisation-unifrog)
- [Extension relais – Polarisation Electrofrog](#-extension-relais--polarisation-electrofrog)
- [Extension relais – Contact ouvert (usage général)](#️-extension-relais--contact-ouvert-usage-général)
- [Dételeurs et autres charges inductives](#-dételeurs-et-autres-charges-inductives)
- [Configuration du OS-Solenoid-Decoder](#️-configuration-du-os-solenoid-decoder)
- [Comportement des LED en mode de fonctionnement](#-comportement-des-led-en-mode-de-fonctionnement)
- [Entrée en mode de configuration](#-entrée-en-mode-de-configuration)
- [Avant de commencer](#-avant-de-commencer)
- [Vue d'ensemble des menus](#-vue-densemble-des-menus)
- [Menu 1 : Assignation d'adresse DCC](#-menu-1--assignation-dadresse-dcc)
- [Menu 2 : Sélection du type de sortie](#-menu-2--sélection-du-type-de-sortie)
- [Menu 3 : Configuration du temps d'impulsion](#-menu-3--configuration-du-temps-dimpulsion)
- [Menu 4 : Rapport cyclique PWM](#-menu-4--rapport-cyclique-pwm)
- [Menu 5 : Réglages globaux et préréglages](#-menu-5--réglages-globaux-et-préréglages)
- [Explication de la commande par fonctions de locomotive](#-explication-de-la-commande-par-fonctions-de-locomotive)

---

## 🔧 Caractéristiques

- **Jusqu'à 5 A de courant de sortie total** — pilote des solénoïdes lourds, relais ou moteurs d'aiguille sans amplificateurs externes
- **Borniers à vis enfichables** — facilite le précâblage et permet un retrait ou un remplacement rapide du décodeur
- **Modes de sortie multiples :**
  - Double Impulsion (par défaut)
  - Simple Impulsion
  - Double Continu
  - Simple Continu
  - Double Impulsion avec relais Electrofrog
- **Une sortie à la fois** — le décodeur commute une paire de sorties à la fois pour éviter les surcharges
- **Support optionnel du module CDU** — réduit la consommation d'énergie et prolonge la durée de vie des moteurs d'aiguille
- **Détection et protection contre les surcharges** — les sorties sont automatiquement désactivées en cas de surcharge détectée
- **Configuration via commandes DCC uniquement** — aucun logiciel ou matériel de programmation requis
- **Préréglages de configuration prédéfinis** — basculez rapidement toutes les sorties en mode impulsion, continu ou electrofrog avec une seule commande DCC
- **Commande par fonctions de locomotive** (F1–F16) — pour une commutation rapide via des manettes comme la Roco Lokmaus ou la Multimaus
- **Support du décalage d'adresse Roco** — prise en charge intégrée du décalage de 4 adresses Roco
- **Extensible avec cartes relais et transistors :**
  - Module relais double pour la polarisation des aiguilles Electrofrog
  - Relais bistable simple pour la commutation de polarité Unifrog
  - Modules relais à contact ouvert pour la commande DCC de relais à usage général
  - Module pilote transistor pour les moteurs d'aiguille à deux fils

---

## 🔌 Connexion du décodeur

Le OS-Solenoid-Decoder suit une disposition de câblage claire et cohérente. L'alimentation est connectée en haut, les sorties sont des deux côtés.

---

## 🔋 Alimentation électrique

- Connectez soit la tension de voie DCC, soit une alimentation DC (max. 19 V) au décodeur.
- Le signal DCC et les lignes d'alimentation se connectent depuis le côté supérieur du décodeur.
- ⚠️ N'utilisez pas de tension AC — cela endommagerait le décodeur.

---

## ⚡ Sorties solénoïde

Le décodeur fournit 8 blocs de sortie double, conçus pour les moteurs d'aiguille classiques à double bobine.

Chaque bloc de sortie comporte :

- Deux bornes à vis extérieures — pour la bobine gauche et droite (A et B)
- Une borne centrale — pour le fil commun (COM), partagé entre les deux bobines

Cette disposition vous permet de :

- Piloter jusqu'à 8 moteurs d'aiguille à double bobine (par ex. PECO, Fleischmann, Märklin, Roco, Piko, Hornby)
- Ou connecter directement des moteurs d'aiguille à 3 fils comme le MTB MP-1

Les sorties sont regroupées par paires avec un marquage clair A, COM et B.

Décodeur solénoïde avec 8 moteurs d'aiguille à double bobine connectés

Bien que le décodeur ne soit pas conçu pour la commande de signaux, il peut piloter de simples signaux à deux aspects en utilisant les mêmes sorties.

Exemple de câblage d'un signal à deux aspects

---

## 🔌 Extension relais – Polarisation Unifrog

Cette extension alimente automatiquement le cœur des aiguilles Unifrog à l'aide de relais à accrochage automatique.

- La carte relais se compose de quatre petites unités relais, qui peuvent être séparées par rupture si vous en avez besoin de moins de quatre.

Carte d'extension à relais bistables

- Les relais sont verrouillés par le même signal utilisé pour déclencher le moteur d'aiguille — aucune configuration supplémentaire n'est nécessaire.
- Chaque unité relais commute la polarité du cœur en fonction du sens de l'aiguille.

Avec un relais par aiguille, cette extension gère jusqu'à 8 cœurs Unifrog avec deux cartes.

Extension relais montée sur le décodeur pour le câblage Unifrog

- La carte relais se branche directement dans l'en-tête d'extension du décodeur, mais peut également être montée à distance près de l'aiguille.

Exemple d'extension relais montée à distance

Ce module relais est également compatible avec d'autres décodeurs solénoïde.

---

## ⚡ Extension relais – Polarisation Electrofrog

Les aiguilles Electrofrog nécessitent deux commutateurs relais par aiguille :

1. Un pour déconnecter le cœur avant la commutation du moteur d'aiguille
2. Un pour le reconnecter avec la polarité correcte ensuite

Cette extension gère automatiquement cette séquence. Elle se compose de quatre modules relais doubles, liés de façon permanente.

- Elle se branche sur le côté gauche du décodeur (marqué pour l'utilisation electrofrog).
- Chaque paire de relais est liée à une sortie solénoïde : sortie 1 → paire relais 1, sortie 2 → paire relais 2, etc.
- Ces modules ne peuvent pas être séparés, car ils partagent l'alimentation de voie et la logique interne.

Le décodeur dispose d'un mode préréglage spécial qui active la séquence de commutation electrofrog.
Si la polarité du cœur est incorrecte après l'installation, retournez les cavaliers sur le module relais pour la corriger — aucune reprogrammation nécessaire.

---

## ⚙️ Extension relais – Contact ouvert (usage général)

Pour commuter des dispositifs externes (éclairages, signaux, circuits logiques) à l'aide de simples contacts relais :

- Chaque unité fournit un relais inverseur (NO/NC), commandable via DCC.
- Jusqu'à 16 contacts relais individuellement adressables lorsque entièrement équipé.
- Les modules se branchent directement dans le décodeur ou peuvent être utilisés à distance avec des fils.
- Disponible en version DIY traversante et en version SMD compacte.

Comme les cartes relais Unifrog, ces modules peuvent être séparés par rupture et réutilisés avec d'autres décodeurs DCC solénoïde.

Modules relais à usage général montés sur le décodeur

Détail du module relais à usage général

L'extension relais à usage général peut également polariser les aiguilles Electrofrog avec un câblage légèrement plus élaboré :

- Utilisez les contacts NO (Normalement Ouvert)
- Reliez en boucle les deux contacts COM et connectez-les au cœur
- Connectez les contacts NO aux rails d'alimentation de voie

Câblage electrofrog avec modules relais à usage général

Si un cœur se retrouve avec la mauvaise polarité, échangez les deux fils d'alimentation de voie (comme indiqué pour le cœur 4 dans le schéma ci-dessus).

---

## 🧲 Dételeurs et autres charges inductives

Le OS-Solenoid-Decoder peut piloter des dételeurs, des électroaimants et d'autres charges inductives en plus des moteurs d'aiguille.

- **Mode Simple Impulsion** (recommandé) — envoie une brève impulsion de courant, idéal pour les bobines à ressort ou sensibles au temps
- **Mode Simple Continu** — maintient la sortie continuellement activée, utile pour les relais monostables ou les dispositifs ON/OFF simples

Exemple de câblage de dételeur

⚠️ Les dételeurs peuvent surchauffer si la commutation est trop longue — vérifiez toujours la fiche technique de votre marque de voie et maintenez les temps d'impulsion courts.

---

## ⚙️ Configuration du OS-Solenoid-Decoder

Par défaut, le décodeur fonctionne en mode normal à la mise sous tension. Deux LED fournissent un retour visuel sur ce qui se passe.

---

## 🔦 Comportement des LED en mode de fonctionnement

| Motif LED | Mode |
|---|---|
| Les deux LED clignotent | Double Impulsion (par défaut) |
| Une LED clignote, l'autre ÉTEINTE | Simple Impulsion |
| Les deux LED allumées | Double Continu |
| Une LED allumée | Simple Continu |
| Une LED allumée + l'autre LED clignote | Mode Electrofrog (double impulsion + relais de cœur) |

Lorsque des sorties sont configurées avec des types mixtes, la LED gauche reste allumée et la LED droite clignote une fois en continu pour indiquer le mode de configuration mixte.

---

## 🧰 Entrée en mode de configuration

Pour entrer en mode de configuration :

1. Maintenez le bouton de configuration enfoncé. La LED droite commence à clignoter :
   - 1 clignotement = Menu 1
   - 2 clignotements = Menu 2
   - ... jusqu'au Menu 5
2. Relâchez le bouton lorsque la LED atteint le menu souhaité.

Une fois dans un menu :

- La LED gauche clignote le même nombre de fois que le numéro du menu (ex. 3 clignotements = Menu 3).
- Appuyez à nouveau sur le bouton pour quitter le menu, sauf indication contraire dans la section ci-dessous.

Organigramme du menu de configuration

---

## 🧠 Avant de commencer

Si vous prévoyez d'utiliser des types de sortie mixtes (par ex. Simple Continu pour les relais avec Double Impulsion pour les moteurs d'aiguille), planifiez d'abord vos assignations de sorties sur papier.

**Exemple :** si les sorties 5 à 8 doivent être en Simple Continu (pour 8 relais) et les sorties 1 à 4 en Double Continu (pour les moteurs d'aiguille), vous devez :

1. Utiliser le Menu 2 pour assigner les types de sortie corrects
2. Puis utiliser le Menu 1 pour assigner les adresses DCC avec soin, car les sorties simples utilisent plus d'adresses

---

## 📖 Vue d'ensemble des menus

| Menu | Fonction |
|---|---|
| 1 | Assignation d'adresse DCC |
| 2 | Sélection du type de sortie |
| 3 | Configuration du temps d'impulsion |
| 4 | Rapport cyclique PWM |
| 5 | Réglages globaux et préréglages |

---

## 🟠 Menu 1 : Assignation d'adresse DCC

Utilisez ce menu pour assigner des adresses DCC à chaque sortie.

Règles :
- Les modes Double utilisent 1 adresse
- Les modes Simple utilisent 2 adresses (A et B séparément)

Si vous assignez l'adresse 20 à la sortie 1 en mode Simple, elle occupera les adresses 20 et 21. La sortie 2 commencera alors à 22. Le décodeur gère ce décalage automatiquement.

Sélection des sorties :
- Envoyez l'adresse DCC accessoire 1 à 8 pour sélectionner une sortie.
- Envoyez une seconde adresse pour l'assigner à cette sortie.
- Envoyez l'adresse 9 comme sélecteur pour appliquer la même adresse à toutes les sorties simultanément.

En mode d'adressage unique, vous pouvez donner à chaque sortie une adresse personnalisée, y compris des numéros répétés ou sautés. Le décodeur retourne immédiatement en mode de fonctionnement après l'assignation, sauf si le mode unique est actif — dans ce cas, appuyez sur le bouton de configuration pour quitter.

---

## 🟡 Menu 2 : Sélection du type de sortie

Chaque sortie peut être réglée sur l'un des types suivants :

| ID de type | Description du mode |
|---|---|
| 1 | Double Impulsion (par défaut) |
| 2 | Double Continu |
| 3 | Simple Impulsion |
| 4 | Simple Continu |
| 5 | Double Impulsion avec support du relais Electrofrog |

En mode Electrofrog, les sorties 1 à 4 commandent les paires de relais des sorties 8 à 5 dans l'ordre inverse (sortie 1 → relais 8, sortie 2 → relais 7, etc.).

Sélectionnez la sortie à configurer en envoyant l'adresse DCC 1 à 8.

---

## 🔵 Menu 3 : Configuration du temps d'impulsion

Affinez le temps d'impulsion pour chaque sortie.

**Sorties Simple Impulsion :**
- Le temps est réglé en secondes entières
- Adresse 10 = 10 secondes
- Plage : 1 à 4096 secondes
- Par défaut : 5 s

**Sorties Double Impulsion :**
- Le temps est réglé par pas de 10 ms
- Adresse 1 = 10 ms
- Maximum : 40,9 s (4096 × 10 ms)
- Par défaut : 50 ms

Envoyez l'adresse 9 pour appliquer le même temps à toutes les sorties simultanément.

---

## 🟣 Menu 4 : Rapport cyclique PWM

Disponible pour les sorties configurées en mode Continu (Simple ou Double).

Le PWM réduit la puissance moyenne délivrée — idéal pour les moteurs lents comme le MTB MP-1.

- Fréquence PWM : 50 Hz
- Adresse 10 = rapport cyclique 100% (par défaut ; pleine puissance, sans PWM)

| Adresse | Rapport cyclique |
|---|---|
| 1 | 10% |
| 2 | 20% |
| ... | ... |
| 10 | 100% (par défaut) |

Envoyez l'adresse 9 pour appliquer le même rapport cyclique à toutes les sorties.

---

## 🔘 Menu 5 : Réglages globaux et préréglages

**Préréglages — régler tous les types de sortie en une fois :**

| Adresse | Mode préréglé |
|---|---|
| 1 | Double Impulsion (par défaut) |
| 2 | Double Continu |
| 3 | Simple Impulsion |
| 4 | Simple Continu |
| 5 | Double Impulsion avec mode Electrofrog |

**Options spéciales :**

| Adresse | Réglage |
|---|---|
| 20 | Désactiver les adresses de sortie uniques (par défaut) |
| 21 | Activer les adresses de sortie uniques |
| 30 | Désactiver le support des commandes DCC EXT (par défaut) |
| 31 | Activer le support de longueur d'impulsion DCC EXT |
| 40 | Désactiver la commande par fonctions de locomotive (par défaut) |
| 41 | Activer les fonctions locomotive (F1–F16, 1 adresse) |
| 42 | Activer les fonctions locomotive (F1–F4, 2+ adresses) |
| 996 / 1000 | Désactiver le décalage d'adresse Roco de 4 (par défaut) |
| 997 / 1001 | Activer le décalage d'adresse Roco de 4 |

---

## 📟 Explication de la commande par fonctions de locomotive

Vous pouvez commander le décodeur en utilisant les touches de fonction de locomotive (F1–F16) au lieu des commandes DCC accessoire.

**Avantages :**
- Fonctionne avec des manettes comme la Roco Lokmaus 2
- Commutation très rapide — idéal pour la commande rapide du réseau

**Modes :**
- **Mode F1–F16 :** utilise 1 adresse de locomotive
- **Mode F1–F4 :** utilise 2 adresses de locomotive ou plus (utile pour les manettes qui ne prennent en charge que F1–F4)

L'adresse de locomotive utilisée correspond à l'adresse DCC assignée à la sortie 1.

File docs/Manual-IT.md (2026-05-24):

> 🌐 &nbsp; [🇬🇧 EN](Manual-EN.md) &nbsp;|&nbsp; [🇩🇪 DE](Manual-DE.md) &nbsp;|&nbsp; [🇫🇷 FR](Manual-FR.md) &nbsp;|&nbsp; [🇳🇱 NL](Manual-NL.md) &nbsp;|&nbsp; [🇪🇸 ES](Manual-ES.md) &nbsp;|&nbsp; 🇮🇹 IT &nbsp;|&nbsp; [🇵🇱 PL](Manual-PL.md) &nbsp;|&nbsp; [🇨🇿 CS](Manual-CS.md) &nbsp;|&nbsp; [🇩🇰 DA](Manual-DA.md) &nbsp;|&nbsp; [🇳🇴 NO](Manual-NO.md) &nbsp;|&nbsp; [🇸🇪 SV](Manual-SV.md) &nbsp;|&nbsp; [🇭🇺 HU](Manual-HU.md) &nbsp;|&nbsp; [🇵🇹 PT](Manual-PT.md)

# OS-Solenoid-Decoder

## 📘 Introduzione

L'OS-Solenoid-Decoder è un decoder DCC per accessori semplice e potente per la commutazione di:

- Scambi (motori di scambio)
- Relè
- Disaccoppiatori
- Qualsiasi altro dispositivo a solenoide

È in grado di gestire carichi fino a 5 A e supporta quasi tutti i tipi di motori di scambio.
Può essere utilizzato anche in combinazione con i moduli OS-relays per gestire la polarizzazione del frog sia per scambi Electrofrog che Unifrog.

Questo decoder è progettato per essere:

- **Facile da cablare** — i morsetti a vite innestabili semplificano la pre-installazione e consentono una rapida rimozione o sostituzione
- **Facile da configurare** — utilizza solo comandi DCC standard per accessori; nessun computer, nessun CV, nessun POM
- **Modulare** — schede di espansione opzionali per relè e transistor
- **Robusto** — protezione integrata contro il sovraccarico

Che si stia costruendo un grande plastico o si voglia semplicemente qualcosa che funzioni senza problemi: questo decoder è fatto per portare a termine il lavoro.

---

## Indice

- [Caratteristiche](#-caratteristiche)
- [Collegamento del Decoder](#-collegamento-del-decoder)
- [Alimentazione](#-alimentazione)
- [Uscite Solenoide](#-uscite-solenoide)
- [Estensione Relè – Polarizzazione Unifrog](#-estensione-relè--polarizzazione-unifrog)
- [Estensione Relè – Polarizzazione Electrofrog](#-estensione-relè--polarizzazione-electrofrog)
- [Estensione Relè – Contatto Aperto (Uso Generale)](#️-estensione-relè--contatto-aperto-uso-generale)
- [Disaccoppiatori e Altri Carichi Induttivi](#-disaccoppiatori-e-altri-carichi-induttivi)
- [Configurazione dell'OS-Solenoid-Decoder](#️-configurazione-dellos-solenoid-decoder)
- [Comportamento dei LED in Modalità Operativa](#-comportamento-dei-led-in-modalità-operativa)
- [Accesso alla Modalità di Configurazione](#-accesso-alla-modalità-di-configurazione)
- [Prima di Iniziare](#-prima-di-iniziare)
- [Panoramica del Menu](#-panoramica-del-menu)
- [Menu 1: Assegnazione Indirizzo DCC](#-menu-1-assegnazione-indirizzo-dcc)
- [Menu 2: Selezione Tipo Uscita](#-menu-2-selezione-tipo-uscita)
- [Menu 3: Configurazione Tempo Impulso](#-menu-3-configurazione-tempo-impulso)
- [Menu 4: Ciclo di Lavoro PWM](#-menu-4-ciclo-di-lavoro-pwm)
- [Menu 5: Impostazioni Globali e Preset](#-menu-5-impostazioni-globali-e-preset)
- [Spiegazione del Controllo tramite Funzioni Locomotiva](#-spiegazione-del-controllo-tramite-funzioni-locomotiva)

---

## 🔧 Caratteristiche

- **Fino a 5 A di corrente di uscita totale** — aziona solenoidi pesanti, relè o motori di scambio senza booster esterni
- **Morsetti a vite innestabili** — semplificano la pre-installazione e consentono la rapida rimozione o sostituzione del decoder
- **Modalità di uscita multiple:**
  - Doppio Impulso (predefinito)
  - Impulso Singolo
  - Doppio Stabile
  - Singolo Stabile
  - Doppio Impulso con Relè Electrofrog
- **Una uscita alla volta** — il decoder commuta una coppia di uscite alla volta per prevenire il sovraccarico
- **Supporto opzionale modulo CDU** — riduce il consumo energetico e prolunga la vita dei motori di scambio
- **Rilevamento e protezione dal sovraccarico** — le uscite vengono disabilitate automaticamente in caso di sovraccarico
- **Configurazione tramite soli comandi DCC** — nessun software o hardware di programmazione richiesto
- **Preset di configurazione predefiniti** — impostare rapidamente tutte le uscite in modalità impulso, stabile o electrofrog con un singolo comando DCC
- **Controllo tramite funzioni locomotiva** (F1–F16) — per commutazione rapida con regolatori come Roco Lokmaus o Multimaus
- **Supporto offset indirizzo Roco** — supporto integrato per l'offset a 4 indirizzi Roco
- **Espandibile con schede relè e transistor:**
  - Modulo relè doppio per la polarizzazione degli scambi Electrofrog
  - Relè singolo a mantenimento per la commutazione della polarità Unifrog
  - Moduli relè a contatto aperto per controllo relè DCC a uso generale
  - Modulo driver transistor per motori di scambio a 2 fili

---

## 🔌 Collegamento del Decoder

L'OS-Solenoid-Decoder segue uno schema di cablaggio chiaro e coerente. L'alimentazione si collega in alto, le uscite si trovano su entrambi i lati.

---

## 🔋 Alimentazione

- Collegare la tensione del binario DCC oppure un'alimentazione DC (max 19 V) al decoder.
- Sia il segnale DCC che le linee di alimentazione si collegano dal lato superiore del decoder.
- ⚠️ Non utilizzare tensione AC — danneggerà il decoder.

---

## ⚡ Uscite Solenoide

Il decoder fornisce 8 blocchi di uscita doppia, progettati per i classici motori di scambio a doppia bobina.

Ogni blocco di uscita comprende:

- Due morsetti a vite esterni — per la bobina sinistra e destra (A e B)
- Un morsetto centrale — per il filo comune (COM), condiviso tra le due bobine

Questo schema consente di:

- Azionare fino a 8 motori di scambio a doppia bobina (ad es. PECO, Fleischmann, Märklin, Roco, Piko, Hornby)
- Oppure collegare direttamente motori di scambio a 3 fili come il MTB MP-1

Le uscite sono raggruppate in coppie con etichettatura chiara A, COM e B.

Decoder solenoide con 8 motori di scambio a doppia bobina collegati

Sebbene il decoder non sia progettato per il controllo di segnali, può azionare semplici segnali a due aspetti utilizzando le stesse uscite.

Esempio di cablaggio di un segnale a due aspetti

---

## 🔌 Estensione Relè – Polarizzazione Unifrog

Questa estensione alimenta automaticamente il frog degli scambi Unifrog tramite relè a mantenimento automatico.

- La scheda relè è composta da quattro piccole unità relè, che possono essere separate se se ne necessitano meno di quattro.

Scheda estensione relè a mantenimento

- I relè vengono eccitati dallo stesso segnale usato per attivare il motore di scambio — non è necessaria alcuna configurazione aggiuntiva.
- Ogni unità relè commuta la polarità del frog in base alla direzione dello scambio.

Con un relè per scambio, questa estensione gestisce fino a 8 frog Unifrog utilizzando due schede.

Estensione relè montata sul decoder per il cablaggio Unifrog

- La scheda relè si innesta direttamente nel connettore di espansione del decoder, ma può anche essere montata in remoto vicino allo scambio.

Esempio di estensione relè montata in remoto

Questo modulo relè è compatibile anche con altri decoder per solenoidi.

---

## ⚡ Estensione Relè – Polarizzazione Electrofrog

Gli scambi Electrofrog richiedono due commutazioni relè per scambio:

1. Una per disconnettere il frog prima di azionare il motore dello scambio
2. Una per ricollegarlo con la polarità corretta dopo la commutazione

Questa estensione gestisce automaticamente quella sequenza. È composta da quattro moduli relè doppi, collegati in modo permanente.

- Si innesta sul lato sinistro del decoder (contrassegnato per uso Electrofrog).
- Ogni coppia di relè è collegata a un'uscita solenoide: uscita 1 → coppia relè 1, uscita 2 → coppia relè 2, ecc.
- Questi moduli non possono essere separati, poiché condividono l'alimentazione del binario e la logica interna.

Il decoder dispone di una speciale modalità preset che attiva la sequenza di commutazione Electrofrog.
Se la polarità del frog risulta errata dopo l'installazione, invertire i jumper sul modulo relè per correggerla — senza necessità di riprogrammazione.

---

## ⚙️ Estensione Relè – Contatto Aperto (Uso Generale)

Per la commutazione di dispositivi esterni (luci, segnali, circuiti logici) tramite semplici contatti relè:

- Ogni unità fornisce un relè a doppia inversione (NO/NC), controllabile via DCC.
- Fino a 16 contatti relè indirizzabili individualmente quando completamente popolato.
- I moduli si innestano direttamente nel decoder oppure possono essere utilizzati in remoto con fili.
- Disponibili in versione fai-da-te a foro passante e in versione compatta SMD.

Come le schede relè Unifrog, questi moduli possono essere separati e riutilizzati con altri decoder DCC per solenoidi.

Moduli relè a uso generale montati sul decoder

Dettaglio modulo relè a uso generale

L'estensione relè a uso generale può anche polarizzare gli scambi Electrofrog con un cablaggio leggermente più complesso:

- Utilizzare i contatti NO (Normalmente Aperto)
- Unire entrambi i morsetti COM e collegarli al frog
- Collegare i contatti NO alle rotaie di alimentazione

Cablaggio Electrofrog con moduli relè a uso generale

Se un frog risulta con polarità errata, invertire i due fili di alimentazione del binario (come mostrato per il frog 4 nel diagramma sopra).

---

## 🧲 Disaccoppiatori e Altri Carichi Induttivi

L'OS-Solenoid-Decoder può azionare disaccoppiatori, elettromagneti e altri carichi induttivi oltre ai motori di scambio.

- **Modalità Impulso Singolo** (consigliata) — invia una breve scarica di corrente, ideale per bobine a molla o sensibili al tempo
- **Modalità Singolo Stabile** — mantiene l'uscita continuamente attiva, utile per relè monostabili o semplici dispositivi ON/OFF

Esempio di cablaggio disaccoppiatore

⚠️ I disaccoppiatori possono surriscaldarsi se azionati troppo a lungo — verificare sempre il foglio dati per la propria marca di binari e mantenere i tempi di impulso brevi.

---

## ⚙️ Configurazione dell'OS-Solenoid-Decoder

Per impostazione predefinita il decoder funziona in modalità normale quando viene alimentato. Due LED forniscono un feedback visivo su ciò che sta accadendo.

---

## 🔦 Comportamento dei LED in Modalità Operativa

| Pattern LED | Modalità |
|---|---|
| Entrambi i LED lampeggiano | Doppio Impulso (predefinito) |
| Un LED lampeggia, uno SPENTO | Impulso Singolo |
| Entrambi i LED ACCESI | Doppio Stabile |
| Un LED ACCESO | Singolo Stabile |
| Un LED ACCESO + altro LED lampeggiante | Modalità Electrofrog (doppio impulso + relè frog) |

Quando le uscite sono configurate con tipi misti, il LED sinistro rimane ACCESO e quello destro lampeggia continuamente una volta per indicare la modalità a configurazione mista.

---

## 🧰 Accesso alla Modalità di Configurazione

Per accedere alla modalità di configurazione:

1. Tenere premuto il pulsante di configurazione. Il LED destro inizia a lampeggiare:
   - 1 lampeggio = Menu 1
   - 2 lampeggi = Menu 2
   - ... fino al Menu 5
2. Rilasciare il pulsante quando il LED raggiunge il menu desiderato.

Una volta in un menu:

- Il LED sinistro lampeggia lo stesso numero di volte del numero del menu (ad es. 3 lampeggi = Menu 3).
- Premere di nuovo il pulsante per uscire dal menu, a meno che la sezione sottostante non indichi diversamente.

Diagramma di flusso del menu di configurazione

---

## 🧠 Prima di Iniziare

Se si prevede di utilizzare tipi di uscita misti (ad es. Singolo Stabile per relè insieme a Doppio Impulso per motori di scambio), pianificare prima su carta le assegnazioni delle uscite.

**Esempio:** se le uscite 5–8 devono essere Singolo Stabile (per 8 relè) e le uscite 1–4 devono essere Doppio Stabile (per motori di scambio), è necessario:

1. Usare il Menu 2 per assegnare i tipi di uscita corretti
2. Poi usare il Menu 1 per assegnare attentamente gli indirizzi DCC, poiché le uscite singole utilizzano più indirizzi

---

## 📖 Panoramica del Menu

| Menu | Funzione |
|---|---|
| 1 | Assegnazione Indirizzo DCC |
| 2 | Selezione Tipo Uscita |
| 3 | Configurazione Tempo Impulso |
| 4 | Ciclo di Lavoro PWM |
| 5 | Impostazioni Globali e Preset |

---

## 🟠 Menu 1: Assegnazione Indirizzo DCC

Utilizzare questo menu per assegnare indirizzi DCC a ciascuna uscita.

Regole:
- Le modalità doppie utilizzano 1 indirizzo
- Le modalità singole utilizzano 2 indirizzi (A e B separatamente)

Se si assegna l'indirizzo 20 all'Uscita 1 in modalità singola, occuperà gli indirizzi 20 e 21. L'Uscita 2 inizierà quindi dall'indirizzo 22. Il decoder gestisce automaticamente questo scorrimento.

Selezione delle uscite:
- Inviare l'indirizzo DCC accessori da 1 a 8 per selezionare un'uscita.
- Inviare un secondo indirizzo per assegnarlo a quell'uscita.
- Inviare l'indirizzo 9 come selettore per applicare lo stesso indirizzo a tutte le uscite contemporaneamente.

In modalità di indirizzamento univoco, è possibile assegnare a ogni uscita un indirizzo personalizzato, inclusi numeri ripetuti o saltati. Il decoder torna immediatamente alla modalità operativa dopo l'assegnazione, a meno che la modalità univoca non sia attiva — in quel caso premere il pulsante di configurazione per uscire.

---

## 🟡 Menu 2: Selezione Tipo Uscita

Ogni uscita può essere impostata su uno dei seguenti tipi:

| ID Tipo | Descrizione Modalità |
|---|---|
| 1 | Doppio Impulso (predefinito) |
| 2 | Doppio Stabile |
| 3 | Impulso Singolo |
| 4 | Singolo Stabile |
| 5 | Doppio Impulso con supporto relè Electrofrog |

In modalità Electrofrog, le uscite 1–4 controllano le coppie di relè sulle uscite 8–5 in ordine inverso (uscita 1 → relè 8, uscita 2 → relè 7, ecc.).

Selezionare quale uscita configurare inviando l'indirizzo DCC da 1 a 8.

---

## 🔵 Menu 3: Configurazione Tempo Impulso

Regolazione fine del tempo di impulso per ciascuna uscita.

**Uscite a Impulso Singolo:**
- Il tempo è impostato in secondi interi
- Indirizzo 10 = 10 secondi
- Intervallo: 1–4096 secondi
- Predefinito: 5 s

**Uscite a Doppio Impulso:**
- Il tempo è impostato in passi da 10 ms
- Indirizzo 1 = 10 ms
- Massimo: 40,9 s (4096 × 10 ms)
- Predefinito: 50 ms

Inviare l'indirizzo 9 per applicare lo stesso tempo a tutte le uscite contemporaneamente.

---

## 🟣 Menu 4: Ciclo di Lavoro PWM

Disponibile per le uscite configurate in modalità Stabile (Singolo o Doppio).

Il PWM riduce la potenza media erogata — ideale per motori lenti come il MTB MP-1.

- Frequenza PWM: 50 Hz
- Indirizzo 10 = 100% ciclo di lavoro (predefinito; piena potenza, nessun PWM)

| Indirizzo | Ciclo di Lavoro |
|---|---|
| 1 | 10% |
| 2 | 20% |
| ... | ... |
| 10 | 100% (predefinito) |

Inviare l'indirizzo 9 per applicare lo stesso ciclo di lavoro a tutte le uscite.

---

## 🔘 Menu 5: Impostazioni Globali e Preset

**Preset — imposta tutti i tipi di uscita contemporaneamente:**

| Indirizzo | Modalità Preset |
|---|---|
| 1 | Doppio Impulso (predefinito) |
| 2 | Doppio Stabile |
| 3 | Impulso Singolo |
| 4 | Singolo Stabile |
| 5 | Doppio Impulso con modalità Electrofrog |

**Opzioni speciali:**

| Indirizzo | Impostazione |
|---|---|
| 20 | Disabilita indirizzi di uscita univoci (predefinito) |
| 21 | Abilita indirizzi di uscita univoci |
| 30 | Disabilita supporto comandi DCC EXT (predefinito) |
| 31 | Abilita supporto lunghezza impulso DCC EXT |
| 40 | Disabilita controllo tramite funzioni locomotiva (predefinito) |
| 41 | Abilita funzioni locomotiva (F1–F16, 1 indirizzo) |
| 42 | Abilita funzioni locomotiva (F1–F4, 2+ indirizzi) |
| 996 / 1000 | Disabilita offset a 4 indirizzi Roco (predefinito) |
| 997 / 1001 | Abilita offset a 4 indirizzi Roco |

---

## 📟 Spiegazione del Controllo tramite Funzioni Locomotiva

È possibile controllare il decoder tramite i tasti funzione locomotiva (F1–F16) invece dei comandi DCC per accessori.

**Vantaggi:**
- Funziona con regolatori come Roco Lokmaus 2
- Commutazione molto rapida — ideale per un controllo veloce del plastico

**Modalità:**
- **Modalità F1–F16:** utilizza 1 indirizzo locomotiva
- **Modalità F1–F4:** utilizza 2 o più indirizzi locomotiva (utile per regolatori che supportano solo F1–F4)

L'indirizzo locomotiva utilizzato corrisponde all'indirizzo DCC assegnato all'Uscita 1.

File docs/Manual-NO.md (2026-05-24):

> 🌐 &nbsp; [🇬🇧 EN](Manual-EN.md) &nbsp;|&nbsp; [🇩🇪 DE](Manual-DE.md) &nbsp;|&nbsp; [🇫🇷 FR](Manual-FR.md) &nbsp;|&nbsp; [🇳🇱 NL](Manual-NL.md) &nbsp;|&nbsp; [🇪🇸 ES](Manual-ES.md) &nbsp;|&nbsp; [🇮🇹 IT](Manual-IT.md) &nbsp;|&nbsp; [🇵🇱 PL](Manual-PL.md) &nbsp;|&nbsp; [🇨🇿 CS](Manual-CS.md) &nbsp;|&nbsp; [🇩🇰 DA](Manual-DA.md) &nbsp;|&nbsp; 🇳🇴 NO &nbsp;|&nbsp; [🇸🇪 SV](Manual-SV.md) &nbsp;|&nbsp; [🇭🇺 HU](Manual-HU.md) &nbsp;|&nbsp; [🇵🇹 PT](Manual-PT.md)

# OS-Solenoid-Decoder

## 📘 Innledning

OS-Solenoid-Decoder er en enkel, kraftig DCC-tilbehørsdekoder for kobling av:

- Sporskifter (sporskiftemotorer)
- Reléer
- Avkoplere
- Enhver annen solenoidbasert enhet

Den kan håndtere belastninger på opptil 5 A og støtter nesten alle typer sporskiftemotorer.
Den kan også brukes i kombinasjon med OS-relays for å håndtere frog-polarisering for både electrofrog- og unifrog-sporskifter.

Denne dekoderen er utviklet for å være:

- **Enkel å kable** — uttrekkbare skrueterminaler gjør forhåndskabling enkel og muliggjør rask fjerning eller utskiftning
- **Enkel å konfigurere** — bruker kun standard DCC-tilbehørskommandoer; ingen datamaskin, ingen CV, ingen POM
- **Modulær** — valgfrie relé- og transistorutvidelseskort
- **Robust** — innebygd overbelastningsbeskyttelse

Enten du bygger et stort anlegg eller bare vil ha noe som fungerer uten problemer: denne dekoderen er laget for å fullføre jobben.

---

## Innholdsfortegnelse

- [Egenskaper](#-egenskaper)
- [Tilkobling av dekoderen](#-tilkobling-av-dekoderen)
- [Strømforsyning](#-strømforsyning)
- [Solenoidutganger](#-solenoidutganger)
- [Relé-utvidelse – Unifrog-polarisering](#-relé-utvidelse--unifrog-polarisering)
- [Relé-utvidelse – Electrofrog-polarisering](#-relé-utvidelse--electrofrog-polarisering)
- [Relé-utvidelse – Åpen kontakt (generelt formål)](#️-relé-utvidelse--åpen-kontakt-generelt-formål)
- [Avkoplere og andre induktive laster](#-avkoplere-og-andre-induktive-laster)
- [Konfigurering av OS-Solenoid-Decoder](#️-konfigurering-av-os-solenoid-decoder)
- [LED-atferd i driftsmodus](#-led-atferd-i-driftsmodus)
- [Gå inn i konfigurasjonsmodus](#-gå-inn-i-konfigurasjonsmodus)
- [Før du starter](#-før-du-starter)
- [Menyoversikt](#-menyoversikt)
- [Meny 1: DCC-adressetildeling](#-meny-1-dcc-adressetildeling)
- [Meny 2: Valg av utgangstype](#-meny-2-valg-av-utgangstype)
- [Meny 3: Pulstidkonfigurasjon](#-meny-3-pulstidkonfigurasjon)
- [Meny 4: PWM arbeidsyklus](#-meny-4-pwm-arbeidsyklus)
- [Meny 5: Globale innstillinger og forhåndsinnstillinger](#-meny-5-globale-innstillinger-og-forhåndsinnstillinger)
- [Forklaring av lokomotivfunksjonsstyring](#-forklaring-av-lokomotivfunksjonsstyring)

---

## 🔧 Egenskaper

- **Opptil 5 A total utgangsstrøm** — driver tunge solenoider, reléer eller sporskiftemotorer uten eksterne forsterkere
- **Uttrekkbare skrueterminaler** — gjør forhåndskabling enkel og muliggjør rask fjerning eller utskiftning av dekoderen
- **Flere utgangsmoduser:**
  - Dobbel puls (standard)
  - Enkel puls
  - Dobbel stasjonær
  - Enkel stasjonær
  - Dobbel puls med Electrofrog-relé
- **Én utgang av gangen** — dekoderen bytter ett utgangspar av gangen for å forhindre overbelastning
- **Valgfri CDU-modul-støtte** — reduserer strømforbruk og forlenger sporskiftemotorens levetid
- **Overbelastningsdeteksjon og -beskyttelse** — utganger deaktiveres automatisk hvis overbelastning oppdages
- **Konfigurasjon kun via DCC-kommandoer** — ingen programmeringsprogramvare eller -maskinvare nødvendig
- **Forhåndsdefinerte konfigurasjonsforhåndsinnstillinger** — bytt raskt alle utganger til puls-, stasjonær- eller electrofrog-modus med én enkelt DCC-kommando
- **Lokomotivfunksjonsstyring** (F1–F16) — for rask kobling via regulatorer som Roco Lokmaus eller Multimaus
- **Roco-adresseforskyvning støtte** — innebygd støtte for Roco 4-adresseforskyvning
- **Utvidbar med relé- og transistorkort:**
  - Dobbelt relé-modul for electrofrog sporskifte-polarisering
  - Enkelt selvholdende relé for unifrog-polaritetskobling
  - Åpen-kontakt relé-moduler for generell DCC relé-styring
  - Transistordrivermodul for 2-leder sporskiftemotorer

---

## 🔌 Tilkobling av dekoderen

OS-Solenoid-Decoder følger et tydelig og konsistent kablingslayout. Strøm kobles til øverst, utganger er på begge sider.

---

## 🔋 Strømforsyning

- Koble enten DCC sporsspenning eller en DC-strømforsyning (maks. 19 V) til dekoderen.
- Både DCC-signalet og strømlinjene kobles fra toppen av dekoderen.
- ⚠️ Ikke bruk AC-spenning — dette vil skade dekoderen.

---

## ⚡ Solenoidutganger

Dekoderen gir 8 duale utgangsblokker, utviklet for klassiske dobbeltspolesporskiftemotorer.

Hver utgangsblokk har:

- To ytre skrueterminaler — for venstre og høyre spole (A og B)
- Én midtre terminal — for den felles ledningen (COM), delt mellom de to spolene

Dette oppsettet lar deg:

- Drive opptil 8 dobbeltspolesporskiftemotorer (f.eks. PECO, Fleischmann, Märklin, Roco, Piko, Hornby)
- Eller koble til 3-leder sporskiftemotorer som MTB MP-1 direkte

Utganger er gruppert i par med tydelig A-, COM- og B-merking.

Solenoid-dekoder med 8 dobbeltspolesporskiftemotorer tilkoblet

Selv om dekoderen ikke er utformet for signalstyring, kan den drive enkle tosignal-aspekt-signaler ved hjelp av de samme utgangene.

Eksempel på 2-aspekt signalkabling

---

## 🔌 Relé-utvidelse – Unifrog-polarisering

Denne utvidelsen forsyner automatisk frogen til unifrog-sporskifter ved hjelp av selvholdende reléer.

- Relé-kortet består av fire små relé-enheter, som kan brytes fra hverandre hvis du trenger færre enn fire.

Selvholdende relé-utvidelseskort

- Reléene låses av det samme signalet som brukes til å utløse sporskiftemotoren — ingen ekstra konfigurasjon er nødvendig.
- Hver relé-enhet bytter frog-polariteten basert på sporskiftets retning.

Med ett relé per sporskifte håndterer denne utvidelsen opptil 8 unifrog-froger med to kort.

Relé-utvidelse montert på dekoder for unifrog-kabling

- Relé-kortet plugges direkte inn i dekorderens utvidelsesoverskog, men kan også monteres på avstand nær sporskiftet.

Eksempel på fjerntmontert relé-utvidelse

Denne relé-modulen er også kompatibel med andre solenoid-dekodere.

---

## ⚡ Relé-utvidelse – Electrofrog-polarisering

Electrofrog-sporskifter krever to relé-koblere per sporskifte:

1. En for å frakoble frogen før bytting av sporskiftemotoren
2. En for å koble den til igjen med riktig polaritet etterpå

Denne utvidelsen håndterer denne sekvensen automatisk. Den består av fire doble relé-moduler, permanent koblet.

- Den plugges inn i venstre side av dekoderen (merket for electrofrog-bruk).
- Hvert relé-par er koblet til én solenoidutgang: utgang 1 → relé-par 1, utgang 2 → relé-par 2, osv.
- Disse modulene kan ikke skilles fra hverandre, da de deler sporstrøm og intern logikk.

Dekoderen har en spesiell forhåndsinnstillingsmodus som aktiverer electrofrog-koblingssekvensen.
Hvis frog-polariteten er feil etter installasjon, snu jumperne på relé-modulen for å korrigere dette — ingen omprogrammering nødvendig.

---

## ⚙️ Relé-utvidelse – Åpen kontakt (generelt formål)

For kobling av eksterne enheter (lys, signaler, logikkretser) ved hjelp av rene reléekontakter:

- Hver enhet gir et dobbel-kast (NO/NC) relé, kontrollerbart via DCC.
- Opptil 16 individuelt adresserbare reléekontakter når fullt bestykket.
- Modulene plugges direkte inn i dekoderen eller kan brukes på avstand med ledninger.
- Tilgjengelig i en gjennomhulls DIY-versjon og en kompakt SMD-versjon.

Som unifrog relé-kortene kan disse modulene brytes fra hverandre og gjenbrukes med andre DCC solenoid-dekodere.

Generelle relé-moduler montert på dekoderen

Detaljbilde av generell relé-modul

General Purpose relé-utvidelsen kan også polarisere electrofrog-sporskifter med litt mer kabling:

- Bruk NO-kontaktene (Normally Open)
- Koble begge COM-kontaktene sammen og koble dem til frogen
- Koble NO-kontaktene til sporstrømsinnene

Electrofrog-kabling med General Purpose relé-moduler

Hvis en frog ender opp med feil polaritet, bytt de to sporstrømlinjene (som vist for frog 4 i diagrammet ovenfor).

---

## 🧲 Avkoplere og andre induktive laster

OS-Solenoid-Decoder kan drive avkoplere, elektromagneter og andre induktive laster i tillegg til sporskiftemotorer.

- **Enkel puls-modus** (anbefalt) — sender en kort strømpuls, ideell for fjærbelastede eller tidssensitive spoler
- **Enkel stasjonær modus** — holder utgangen kontinuerlig på, nyttig for monostabile reléer eller enkle PÅ/AV-enheter

Eksempel på avkoplingskabling

⚠️ Avkoplere kan overopphetes hvis de kobles inn for lenge — sjekk alltid dataarket for spormerket ditt og hold pulstidene korte.

---

## ⚙️ Konfigurering av OS-Solenoid-Decoder

Som standard opererer dekoderen i normal modus når den settes under spenning. To LED-er gir visuell tilbakemelding om hva som skjer.

---

## 🔦 LED-atferd i driftsmodus

| LED-mønster | Modus |
|---|---|
| Begge LED-er blinker | Dobbel puls (standard) |
| Én LED blinker, én AV | Enkel puls |
| Begge LED-er PÅ | Dobbel stasjonær |
| Én LED PÅ | Enkel stasjonær |
| Én LED PÅ + annen LED blinker | Electrofrog-modus (dobbel puls + frog-relé) |

Når utganger er konfigurert med blandede typer, forblir venstre LED PÅ og høyre LED blinker én gang kontinuerlig for å indikere blandet-konfig-modus.

---

## 🧰 Gå inn i konfigurasjonsmodus

For å gå inn i konfigurasjonsmodus:

1. Hold inne konfigurasjonsknappen. Høyre LED begynner å blinke:
   - 1 blink = Meny 1
   - 2 blink = Meny 2
   - ... opptil Meny 5
2. Slipp knappen når LED-en når menyen du ønsker.

Når du er i en meny:

- Venstre LED blinker samme antall ganger som menynummeret (f.eks. 3 blink = Meny 3).
- Trykk på knappen igjen for å avslutte menyen, med mindre avsnittet nedenfor sier noe annet.

Konfigurasjonsmenyflytkart

---

## 🧠 Før du starter

Hvis du planlegger å bruke blandede utgangstyper (f.eks. Enkel stasjonær for reléer ved siden av Dobbel puls for sporskiftemotorer), planlegg utgangsfordelingene på papir først.

**Eksempel:** hvis utganger 5–8 skal være Enkel stasjonær (for 8 reléer) og utganger 1–4 skal være Dobbel stasjonær (for sporskiftemotorer), må du:

1. Bruke Meny 2 til å tildele de riktige utgangstype
2. Deretter bruke Meny 1 til å tildele DCC-adresser nøye, fordi Enkle utganger bruker flere adresser

---

## 📖 Menyoversikt

| Meny | Funksjon |
|---|---|
| 1 | DCC-adressetildeling |
| 2 | Valg av utgangstype |
| 3 | Pulstidkonfigurasjon |
| 4 | PWM arbeidsyklus |
| 5 | Globale innstillinger og forhåndsinnstillinger |

---

## 🟠 Meny 1: DCC-adressetildeling

Bruk denne menyen til å tildele DCC-adresser til hver utgang.

Regler:
- Doble moduser bruker 1 adresse
- Enkle moduser bruker 2 adresser (A og B separat)

Hvis du tildeler adresse 20 til Utgang 1 i Enkel modus, vil den oppta adressene 20 og 21. Utgang 2 vil da starte på 22. Dekoderen håndterer denne forskyvelssen automatisk.

Velge utganger:
- Send DCC-tilbehørsadresse 1–8 for å velge en utgang.
- Send en andre adresse for å tildele den til den utgangen.
- Send adresse 9 som velger for å anvende samme adresse på alle utganger samtidig.

I unik adresseringsmodus kan du gi hver utgang en egendefinert adresse, inkludert gjentatte eller hoppede numre. Dekoderen returnerer til driftsmodus umiddelbart etter tildeling, med mindre unik modus er aktiv — i så fall trykk på konfig-knappen for å avslutte.

---

## 🟡 Meny 2: Valg av utgangstype

Hver utgang kan settes til én av følgende typer:

| Type-ID | Modusbeskrivelse |
|---|---|
| 1 | Dobbel puls (standard) |
| 2 | Dobbel stasjonær |
| 3 | Enkel puls |
| 4 | Enkel stasjonær |
| 5 | Dobbel puls med Electrofrog relé-støtte |

I Electrofrog-modus styrer utganger 1–4 relé-parene på utganger 8–5 i omvendt rekkefølge (utgang 1 → relé 8, utgang 2 → relé 7, osv.).

Velg hvilken utgang som skal konfigureres ved å sende DCC-adresse 1–8.

---

## 🔵 Meny 3: Pulstidkonfigurasjon

Finjuster pulstiden for hver utgang.

**Enkle puls-utganger:**
- Tid angis i hele sekunder
- Adresse 10 = 10 sekunder
- Område: 1–4096 sekunder
- Standard: 5 s

**Doble puls-utganger:**
- Tid angis i 10 ms-trinn
- Adresse 1 = 10 ms
- Maksimum: 40,9 s (4096 × 10 ms)
- Standard: 50 ms

Send adresse 9 for å anvende samme tid på alle utganger samtidig.

---

## 🟣 Meny 4: PWM arbeidsyklus

Tilgjengelig for utganger konfigurert i Stasjonær modus (Enkel eller Dobbel).

PWM reduserer den gjennomsnittlige effekten som leveres — ideelt for trege motorer som MTB MP-1.

- PWM-frekvens: 50 Hz
- Adresse 10 = 100 % arbeidsyklus (standard; full effekt, ingen PWM)

| Adresse | Arbeidsyklus |
|---|---|
| 1 | 10 % |
| 2 | 20 % |
| ... | ... |
| 10 | 100 % (standard) |

Send adresse 9 for å anvende samme arbeidsyklus på alle utganger.

---

## 🔘 Meny 5: Globale innstillinger og forhåndsinnstillinger

**Forhåndsinnstillinger — angi alle utgangstyper på én gang:**

| Adresse | Forhåndsinnstillingsmodus |
|---|---|
| 1 | Dobbel puls (standard) |
| 2 | Dobbel stasjonær |
| 3 | Enkel puls |
| 4 | Enkel stasjonær |
| 5 | Dobbel puls med Electrofrog-modus |

**Spesielle alternativer:**

| Adresse | Innstilling |
|---|---|
| 20 | Deaktiver unike utgangsadresser (standard) |
| 21 | Aktiver unike utgangsadresser |
| 30 | Deaktiver DCC EXT-kommandostøtte (standard) |
| 31 | Aktiver DCC EXT pulslengde-støtte |
| 40 | Deaktiver lokomotivfunksjonsstyring (standard) |
| 41 | Aktiver lokomotivfunksjoner (F1–F16, 1 adresse) |
| 42 | Aktiver lokomotivfunksjoner (F1–F4, 2+ adresser) |
| 996 / 1000 | Deaktiver Roco 4-adresseforskyvning (standard) |
| 997 / 1001 | Aktiver Roco 4-adresseforskyvning |

---

## 📟 Forklaring av lokomotivfunksjonsstyring

Du kan styre dekoderen ved hjelp av lokomotivfunksjonstaster (F1–F16) i stedet for DCC-tilbehørskommandoer.

**Fordeler:**
- Fungerer med regulatorer som Roco Lokmaus 2
- Svært rask kobling — ideelt for rask anleggsstyring

**Moduser:**
- **F1–F16-modus:** bruker 1 lokoadresse
- **F1–F4-modus:** bruker 2 eller flere lokoadresser (nyttig for regulatorer som kun støtter F1–F4)

Lokoadressen som brukes samsvarer med DCC-adressen tildelt Utgang 1.

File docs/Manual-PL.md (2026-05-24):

> 🌐 &nbsp; [🇬🇧 EN](Manual-EN.md) &nbsp;|&nbsp; [🇩🇪 DE](Manual-DE.md) &nbsp;|&nbsp; [🇫🇷 FR](Manual-FR.md) &nbsp;|&nbsp; [🇳🇱 NL](Manual-NL.md) &nbsp;|&nbsp; [🇪🇸 ES](Manual-ES.md) &nbsp;|&nbsp; [🇮🇹 IT](Manual-IT.md) &nbsp;|&nbsp; 🇵🇱 PL &nbsp;|&nbsp; [🇨🇿 CS](Manual-CS.md) &nbsp;|&nbsp; [🇩🇰 DA](Manual-DA.md) &nbsp;|&nbsp; [🇳🇴 NO](Manual-NO.md) &nbsp;|&nbsp; [🇸🇪 SV](Manual-SV.md) &nbsp;|&nbsp; [🇭🇺 HU](Manual-HU.md) &nbsp;|&nbsp; [🇵🇹 PT](Manual-PT.md)

# OS-Solenoid-Decoder

## 📘 Wprowadzenie

OS-Solenoid-Decoder to prosty, wydajny dekoder akcesoriów DCC do przełączania:

- Zwrotnic (silników zwrotnicowych)
- Przekaźników
- Odsprzęglaczy
- Dowolnych innych urządzeń napędzanych solenoidem

Obsługuje obciążenia do 5 A i współpracuje niemal z każdym typem silnika zwrotnicy.
Może być również używany w połączeniu z OS-relays do obsługi polaryzacji sercówek zarówno dla zwrotnic electrofrog, jak i unifrog.

Ten dekoder został zaprojektowany tak, aby był:

- **Łatwy do okablowania** — wtykowe zaciski śrubowe ułatwiają wstępne okablowanie i umożliwiają szybkie usunięcie lub wymianę
- **Łatwy do konfiguracji** — używa wyłącznie standardowych poleceń akcesoriów DCC; bez komputera, bez CV, bez POM
- **Modułowy** — opcjonalne płytki rozszerzeń przekaźnikowych i tranzystorowych
- **Niezawodny** — wbudowane zabezpieczenie przed przeciążeniem

Niezależnie od tego, czy budujesz duże makietę, czy po prostu chcesz czegoś, co działa bez problemów: ten dekoder jest stworzony do pracy.

---

## Spis treści

- [Właściwości](#-właściwości)
- [Podłączenie dekodera](#-podłączenie-dekodera)
- [Zasilanie](#-zasilanie)
- [Wyjścia solenoidowe](#-wyjścia-solenoidowe)
- [Rozszerzenie przekaźnikowe — polaryzacja Unifrog](#-rozszerzenie-przekaźnikowe--polaryzacja-unifrog)
- [Rozszerzenie przekaźnikowe — polaryzacja Electrofrog](#-rozszerzenie-przekaźnikowe--polaryzacja-electrofrog)
- [Rozszerzenie przekaźnikowe — otwarty styk (ogólnego przeznaczenia)](#️-rozszerzenie-przekaźnikowe--otwarty-styk-ogólnego-przeznaczenia)
- [Odsprzęglacze i inne obciążenia indukcyjne](#-odsprzęglacze-i-inne-obciążenia-indukcyjne)
- [Konfiguracja OS-Solenoid-Decoder](#️-konfiguracja-os-solenoid-decoder)
- [Zachowanie LED w trybie pracy](#-zachowanie-led-w-trybie-pracy)
- [Wchodzenie w tryb konfiguracji](#-wchodzenie-w-tryb-konfiguracji)
- [Przed rozpoczęciem](#-przed-rozpoczęciem)
- [Przegląd menu](#-przegląd-menu)
- [Menu 1: Przypisywanie adresów DCC](#-menu-1-przypisywanie-adresów-dcc)
- [Menu 2: Wybór typu wyjścia](#-menu-2-wybór-typu-wyjścia)
- [Menu 3: Konfiguracja czasu impulsu](#-menu-3-konfiguracja-czasu-impulsu)
- [Menu 4: Wypełnienie PWM](#-menu-4-wypełnienie-pwm)
- [Menu 5: Ustawienia globalne i szablony](#-menu-5-ustawienia-globalne-i-szablony)
- [Wyjaśnienie sterowania funkcjami lokomotywy](#-wyjaśnienie-sterowania-funkcjami-lokomotywy)

---

## 🔧 Właściwości

- **Do 5 A całkowitego prądu wyjściowego** — napędza wydajne solenoidów, przekaźniki lub silniki zwrotnicowe bez zewnętrznych wzmacniaczy
- **Wtykowe zaciski śrubowe** — ułatwiają wstępne okablowanie i umożliwiają szybkie usunięcie lub wymianę dekodera
- **Wiele trybów wyjściowych:**
  - Double Pulse (domyślnie)
  - Single Pulse
  - Double Steady
  - Single Steady
  - Double Pulse z przekaźnikiem Electrofrog
- **Jedno wyjście na raz** — dekoder przełącza jedną parę wyjść na raz, aby zapobiec przeciążeniu
- **Opcjonalna obsługa modułu CDU** — zmniejsza zużycie energii i wydłuża żywotność silnika zwrotnicy
- **Wykrywanie i ochrona przed przeciążeniem** — wyjścia są automatycznie wyłączane po wykryciu przeciążenia
- **Konfiguracja wyłącznie przez polecenia DCC** — nie jest wymagane oprogramowanie ani sprzęt do programowania
- **Predefiniowane szablony konfiguracyjne** — szybkie przełączenie wszystkich wyjść w tryb impulsowy, ciągły lub electrofrog jednym poleceniem DCC
- **Sterowanie funkcjami lokomotywy** (F1–F16) — do szybkiego przełączania za pomocą regulatorów takich jak Roco Lokmaus lub Multimaus
- **Obsługa przesunięcia adresu Roco** — wbudowana obsługa przesunięcia o 4 adresy Roco
- **Rozszerzalne o płytki przekaźnikowe i tranzystorowe:**
  - Podwójny moduł przekaźnikowy do polaryzacji sercówek zwrotnic electrofrog
  - Pojedynczy przekaźnik zatrzaskowy do przełączania biegunowości unifrog
  - Moduły przekaźnikowe z otwartym stykiem do ogólnego sterowania przekaźnikami DCC
  - Moduł sterownika tranzystorowego do dwuprzewodowych silników zwrotnicowych

---

## 🔌 Podłączenie dekodera

OS-Solenoid-Decoder ma przejrzysty i spójny schemat okablowania. Zasilanie jest podłączone od góry, wyjścia są po obu stronach.

---

## 🔋 Zasilanie

- Podłącz napięcie torowe DCC lub zasilacz DC (maks. 19 V) do dekodera.
- Zarówno sygnał DCC, jak i linie zasilające są podłączone od górnej strony dekodera.
- ⚠️ Nie używaj napięcia AC — uszkodzi to dekoder.

---

## ⚡ Wyjścia solenoidowe

Dekoder zapewnia 8 podwójnych bloków wyjściowych, zaprojektowanych dla klasycznych silników zwrotnicowych z podwójną cewką.

Każdy blok wyjściowy ma:

- Dwa zewnętrzne zaciski śrubowe — dla lewej i prawej cewki (A i B)
- Jeden centralny zacisk — dla wspólnego przewodu (COM), współdzielonego przez obie cewki

Ten układ umożliwia:

- Napędzanie do 8 silników zwrotnicowych z podwójną cewką (np. PECO, Fleischmann, Märklin, Roco, Piko, Hornby)
- Lub bezpośrednie podłączenie 3-przewodowych silników zwrotnicowych, takich jak MTB MP-1

Wyjścia są pogrupowane w pary z wyraźnym oznakowaniem A, COM i B.

Dekoder solenoidowy z podłączonymi 8 silnikami zwrotnicowymi z podwójną cewką

Choć dekoder nie jest przeznaczony do sterowania semaforami, może napędzać proste sygnały dwuaspektowe przy użyciu tych samych wyjść.

Przykład okablowania sygnału dwuaspektowego

---

## 🔌 Rozszerzenie przekaźnikowe — polaryzacja Unifrog

To rozszerzenie automatycznie zasila sercówkę zwrotnic unifrog za pomocą przekaźników samoczynnie zatrzaskujących.

- Płytka przekaźnikowa składa się z czterech małych jednostek przekaźnikowych, które można rozdzielić, jeśli potrzebujesz mniej niż czterech.

Płytka rozszerzenia z przekaźnikiem zatrzaskowym

- Przekaźniki są zatrzaskiwane tym samym sygnałem używanym do wyzwalania silnika zwrotnicy — nie jest potrzebna dodatkowa konfiguracja.
- Każda jednostka przekaźnikowa przełącza biegunowość sercówki zgodnie z kierunkiem zwrotnicy.

Z jednym przekaźnikiem na zwrotnicę to rozszerzenie obsługuje do 8 sercówek unifrog przy użyciu dwóch płytek.

Rozszerzenie przekaźnikowe zamontowane na dekoderze do okablowania unifrog

- Płytka przekaźnikowa podłącza się bezpośrednio do nagłówka rozszerzenia dekodera, ale może być również montowana zdalnie, blisko zwrotnicy.

Przykład zdalnie zamontowanego rozszerzenia przekaźnikowego

Ten moduł przekaźnikowy jest również kompatybilny z innymi dekoderami solenoidowymi.

---

## ⚡ Rozszerzenie przekaźnikowe — polaryzacja Electrofrog

Zwrotnice electrofrog wymagają dwóch przełączeń przekaźnikowych na zwrotnicę:

1. Jednego, aby odłączyć sercówkę przed przełączeniem silnika zwrotnicy
2. Jednego, aby ponownie podłączyć ją z prawidłową biegunowością

To rozszerzenie obsługuje tę sekwencję automatycznie. Składa się z czterech podwójnych modułów przekaźnikowych, trwale połączonych.

- Podłącza się do lewej strony dekodera (oznaczonej do użytku electrofrog).
- Każda para przekaźników jest połączona z jednym wyjściem solenoidowym: wyjście 1 → para przekaźników 1, wyjście 2 → para przekaźników 2 itd.
- Tych modułów nie można rozdzielać, ponieważ współdzielą zasilanie torowe i logikę wewnętrzną.

Dekoder ma specjalny tryb szablonu, który aktywuje sekwencję przełączania electrofrog.
Jeśli biegunowość sercówki jest nieprawidłowa po instalacji, przełącz zworki na module przekaźnikowym, aby ją skorygować — nie jest wymagane przeprogramowanie.

---

## ⚙️ Rozszerzenie przekaźnikowe — otwarty styk (ogólnego przeznaczenia)

Do przełączania zewnętrznych urządzeń (oświetlenie, semafory, układy logiczne) przy użyciu zwykłych styków przekaźnikowych:

- Każda jednostka zapewnia przekaźnik przełączający (NO/NC), sterowany przez DCC.
- Do 16 indywidualnie adresowalnych styków przekaźnikowych przy pełnym zaludnieniu.
- Moduły podłączają się bezpośrednio do dekodera lub mogą być używane zdalnie z przewodami.
- Dostępne w wersji DIY THT i kompaktowej wersji SMD.

Podobnie jak płytki przekaźnikowe unifrog, moduły te można rozdzielać i ponownie używać z innymi dekoderami solenoidowymi DCC.

Moduły przekaźnikowe ogólnego przeznaczenia zamontowane na dekoderze

Szczegół modułu przekaźnikowego ogólnego przeznaczenia

Rozszerzenie przekaźnikowe ogólnego przeznaczenia może również polaryzować zwrotnice electrofrog przy nieco większym okablowaniu:

- Użyj styków NO (Normalnie Otwartych)
- Połącz oba zaciski COM razem i podłącz je do sercówki
- Podłącz zaciski NO do przewodów zasilania torowego

Okablowanie electrofrog przy użyciu modułów przekaźnikowych ogólnego przeznaczenia

Jeśli sercówka ma nieprawidłową biegunowość, zamień dwa przewody zasilania torowego (jak pokazano dla sercówki 4 na powyższym schemacie).

---

## 🧲 Odsprzęglacze i inne obciążenia indukcyjne

OS-Solenoid-Decoder może napędzać odsprzęglacze, elektromagnesy i inne obciążenia indukcyjne oprócz silników zwrotnicowych.

- **Tryb Single Pulse** (zalecany) — wysyła krótki impuls prądowy, idealny dla cewek sprężynowych lub czułych na czas
- **Tryb Single Steady** — utrzymuje wyjście ciągle włączone, przydatne dla przekaźników monostabilnych lub prostych urządzeń WŁ/WYŁ

Przykład okablowania odsprzęglacza

⚠️ Odsprzęglacze mogą się przegrzać, jeśli są przełączane zbyt długo — zawsze sprawdzaj dokumentację techniczną swojej marki toru i utrzymuj krótkie czasy impulsu.

---

## ⚙️ Konfiguracja OS-Solenoid-Decoder

Domyślnie dekoder pracuje w trybie normalnym po włączeniu zasilania. Dwie LED zapewniają wizualną informację zwrotną o tym, co się dzieje.

---

## 🔦 Zachowanie LED w trybie pracy

| Wzorzec LED | Tryb |
|---|---|
| Oba LED migają | Double Pulse (domyślnie) |
| Jeden LED miga, jeden WYŁ | Single Pulse |
| Oba LED WŁ | Double Steady |
| Jeden LED WŁ | Single Steady |
| Jeden LED WŁ + drugi LED miga | Tryb Electrofrog (double pulse + przekaźnik sercówki) |

Gdy wyjścia są skonfigurowane w mieszanych typach, lewy LED pozostaje WŁ, a prawy LED miga raz ciąggle, wskazując tryb konfiguracji mieszanej.

---

## 🧰 Wchodzenie w tryb konfiguracji

Aby wejść w tryb konfiguracji:

1. Przytrzymaj przycisk konfiguracji. Prawy LED zaczyna migać:
   - 1 mignięcie = Menu 1
   - 2 mignięcia = Menu 2
   - ... do Menu 5
2. Zwolnij przycisk, gdy LED osiągnie wybrane menu.

Po wejściu w menu:

- Lewy LED miga tyle razy, ile wynosi numer menu (np. 3 mignięcia = Menu 3).
- Naciśnij ponownie przycisk, aby wyjść z menu, chyba że poniższy rozdział mówi inaczej.

Schemat blokowy menu konfiguracji

---

## 🧠 Przed rozpoczęciem

Jeśli planujesz używać mieszanych typów wyjść (np. Single Steady dla przekaźników i Double Pulse dla silników zwrotnicowych), najpierw zaplanuj przypisania wyjść na papierze.

**Przykład:** jeśli wyjścia 5–8 mają być Single Steady (dla 8 przekaźników), a wyjścia 1–4 mają być Double Steady (dla silników zwrotnicowych), musisz:

1. Użyć Menu 2, aby przypisać prawidłowe typy wyjść
2. Następnie użyć Menu 1, aby ostrożnie przypisać adresy DCC, ponieważ wyjścia pojedyncze używają więcej adresów

---

## 📖 Przegląd menu

| Menu | Funkcja |
|---|---|
| 1 | Przypisywanie adresów DCC |
| 2 | Wybór typu wyjścia |
| 3 | Konfiguracja czasu impulsu |
| 4 | Wypełnienie PWM |
| 5 | Ustawienia globalne i szablony |

---

## 🟠 Menu 1: Przypisywanie adresów DCC

Użyj tego menu, aby przypisać adresy DCC do każdego wyjścia.

Zasady:
- Tryby podwójne używają 1 adresu
- Tryby pojedyncze używają 2 adresów (A i B oddzielnie)

Jeśli przypisasz adres 20 do Wyjścia 1 w trybie pojedynczym, zajmie on adresy 20 i 21. Wyjście 2 zacznie się od 22. Dekoder obsługuje to przesunięcie automatycznie.

Wybieranie wyjść:
- Wyślij adres akcesoriów DCC 1–8, aby wybrać wyjście.
- Wyślij drugi adres, aby przypisać go do tego wyjścia.
- Wyślij adres 9 jako selektor, aby jednocześnie zastosować ten sam adres do wszystkich wyjść.

W trybie unikalnego adresowania możesz nadać każdemu wyjściu własny adres, w tym powtórzone lub pomijane numery. Dekoder powraca do trybu pracy natychmiast po przypisaniu, chyba że aktywny jest tryb unikalny — w takim przypadku naciśnij przycisk konfiguracji, aby wyjść.

---

## 🟡 Menu 2: Wybór typu wyjścia

Każde wyjście można ustawić na jeden z następujących typów:

| ID typu | Opis trybu |
|---|---|
| 1 | Double Pulse (domyślnie) |
| 2 | Double Steady |
| 3 | Single Pulse |
| 4 | Single Steady |
| 5 | Double Pulse z obsługą przekaźnika Electrofrog |

W trybie Electrofrog wyjścia 1–4 sterują parami przekaźników na wyjściach 8–5 w odwrotnej kolejności (wyjście 1 → przekaźnik 8, wyjście 2 → przekaźnik 7 itd.).

Wybierz wyjście do skonfigurowania, wysyłając adres DCC 1–8.

---

## 🔵 Menu 3: Konfiguracja czasu impulsu

Dostosuj czas impulsu dla każdego wyjścia.

**Wyjścia Single Pulse:**
- Czas jest ustawiany w całych sekundach
- Adres 10 = 10 sekund
- Zakres: 1–4096 sekund
- Domyślnie: 5 s

**Wyjścia Double Pulse:**
- Czas jest ustawiany w krokach co 10 ms
- Adres 1 = 10 ms
- Maksimum: 40,9 s (4096 × 10 ms)
- Domyślnie: 50 ms

Wyślij adres 9, aby zastosować ten sam czas do wszystkich wyjść jednocześnie.

---

## 🟣 Menu 4: Wypełnienie PWM

Dostępne dla wyjść skonfigurowanych w trybie Steady (Single lub Double).

PWM zmniejsza średnią dostarczaną moc — idealne dla wolnych silników, takich jak MTB MP-1.

- Częstotliwość PWM: 50 Hz
- Adres 10 = 100% wypełnienia (domyślnie; pełna moc, brak PWM)

| Adres | Wypełnienie |
|---|---|
| 1 | 10% |
| 2 | 20% |
| ... | ... |
| 10 | 100% (domyślnie) |

Wyślij adres 9, aby zastosować to samo wypełnienie do wszystkich wyjść.

---

## 🔘 Menu 5: Ustawienia globalne i szablony

**Szablony — ustaw wszystkie typy wyjść jednocześnie:**

| Adres | Tryb szablonu |
|---|---|
| 1 | Double Pulse (domyślnie) |
| 2 | Double Steady |
| 3 | Single Pulse |
| 4 | Single Steady |
| 5 | Double Pulse z trybem Electrofrog |

**Opcje specjalne:**

| Adres | Ustawienie |
|---|---|
| 20 | Wyłącz unikalne adresy wyjść (domyślnie) |
| 21 | Włącz unikalne adresy wyjść |
| 30 | Wyłącz obsługę poleceń DCC EXT (domyślnie) |
| 31 | Włącz obsługę długości impulsu DCC EXT |
| 40 | Wyłącz sterowanie funkcjami lokomotywy (domyślnie) |
| 41 | Włącz funkcje lokomotywy (F1–F16, 1 adres) |
| 42 | Włącz funkcje lokomotywy (F1–F4, 2+ adresów) |
| 996 / 1000 | Wyłącz przesunięcie o 4 adresy Roco (domyślnie) |
| 997 / 1001 | Włącz przesunięcie o 4 adresy Roco |

---

## 📟 Wyjaśnienie sterowania funkcjami lokomotywy

Możesz sterować dekoderem za pomocą klawiszy funkcji lokomotywy (F1–F16) zamiast poleceń akcesoriów DCC.

**Zalety:**
- Działa z regulatorami takimi jak Roco Lokmaus 2
- Bardzo szybkie przełączanie — idealne do szybkiego sterowania makietą

**Tryby:**
- **Tryb F1–F16:** używa 1 adresu lokomotywy
- **Tryb F1–F4:** używa 2 lub więcej adresów lokomotywy (przydatne dla regulatorów obsługujących tylko F1–F4)

Używany adres lokomotywy odpowiada adresowi DCC przypisanemu do Wyjścia 1.

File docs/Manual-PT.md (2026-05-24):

> 🌐 &nbsp; [🇬🇧 EN](Manual-EN.md) &nbsp;|&nbsp; [🇩🇪 DE](Manual-DE.md) &nbsp;|&nbsp; [🇫🇷 FR](Manual-FR.md) &nbsp;|&nbsp; [🇳🇱 NL](Manual-NL.md) &nbsp;|&nbsp; [🇪🇸 ES](Manual-ES.md) &nbsp;|&nbsp; [🇮🇹 IT](Manual-IT.md) &nbsp;|&nbsp; [🇵🇱 PL](Manual-PL.md) &nbsp;|&nbsp; [🇨🇿 CS](Manual-CS.md) &nbsp;|&nbsp; [🇩🇰 DA](Manual-DA.md) &nbsp;|&nbsp; [🇳🇴 NO](Manual-NO.md) &nbsp;|&nbsp; [🇸🇪 SV](Manual-SV.md) &nbsp;|&nbsp; [🇭🇺 HU](Manual-HU.md) &nbsp;|&nbsp; 🇵🇹 PT

# OS-Solenoid-Decoder

## 📘 Introdução

O OS-Solenoid-Decoder é um decoder de acessórios DCC simples e potente para comutar:

- Agulhas (motores de agulha)
- Relés
- Desacopladores
- Qualquer outro dispositivo accionado por solenóide

Consegue suportar cargas de até 5 amperes e é compatível com praticamente qualquer tipo de motor de agulha.
Pode também ser utilizado em combinação com OS-relays para tratar a polarização de frog em agulhas electrofrog e unifrog.

Este decoder foi concebido para ser:

- **Fácil de ligar** — os bornes de parafuso amovíveis facilitam a pré-cablagem e permitem a remoção ou substituição rápida
- **Fácil de configurar** — utiliza apenas comandos de acessório DCC normais; sem computador, sem CV, sem POM
- **Modular** — placas de expansão opcionais com relé e transístor
- **Robusto** — protecção contra sobrecarga integrada

Quer esteja a construir uma grande maquete ou simplesmente queira algo que funcione sem complicações: este decoder foi feito para a tarefa.

---

## Índice

- [Características](#-características)
- [Ligar o Decoder](#-ligar-o-decoder)
- [Alimentação](#-alimentação)
- [Saídas de Solenóide](#-saídas-de-solenóide)
- [Extensão de Relé – Polarização Unifrog](#-extensão-de-relé--polarização-unifrog)
- [Extensão de Relé – Polarização Electrofrog](#-extensão-de-relé--polarização-electrofrog)
- [Extensão de Relé – Contacto Aberto (Uso Geral)](#️-extensão-de-relé--contacto-aberto-uso-geral)
- [Desacopladores e Outras Cargas Indutivas](#-desacopladores-e-outras-cargas-indutivas)
- [Configurar o OS-Solenoid-Decoder](#️-configurar-o-os-solenoid-decoder)
- [Comportamento dos LED no Modo de Operação](#-comportamento-dos-led-no-modo-de-operação)
- [Entrar no Modo de Configuração](#-entrar-no-modo-de-configuração)
- [Antes de Começar](#-antes-de-começar)
- [Visão Geral dos Menus](#-visão-geral-dos-menus)
- [Menu 1: Atribuição de Endereços DCC](#-menu-1-atribuição-de-endereços-dcc)
- [Menu 2: Selecção do Tipo de Saída](#-menu-2-selecção-do-tipo-de-saída)
- [Menu 3: Configuração do Tempo de Impulso](#-menu-3-configuração-do-tempo-de-impulso)
- [Menu 4: Ciclo de Trabalho PWM](#-menu-4-ciclo-de-trabalho-pwm)
- [Menu 5: Definições Globais e Predefinições](#-menu-5-definições-globais-e-predefinições)
- [Controlo por Função de Locomotiva Explicado](#-controlo-por-função-de-locomotiva-explicado)

---

## 🔧 Características

- **Até 5 A de corrente de saída total** — acciona solenóides de alta potência, relés ou motores de agulha sem boosters externos
- **Bornes de parafuso amovíveis** — facilitam a pré-cablagem e permitem a remoção ou substituição rápida do decoder
- **Múltiplos modos de saída:**
  - Impulso Duplo (predefinição)
  - Impulso Simples
  - Contínuo Duplo
  - Contínuo Simples
  - Impulso Duplo com Relé Electrofrog
- **Uma saída de cada vez** — o decoder comuta um par de saídas de cada vez para evitar sobrecarga
- **Suporte opcional de módulo CDU** — reduz o consumo de energia e prolonga a vida do motor de agulha
- **Detecção e protecção contra sobrecarga** — as saídas são automaticamente desactivadas se for detectada uma sobrecarga
- **Configuração apenas por comandos DCC** — sem software nem hardware de programação necessários
- **Predefinições de configuração pré-programadas** — mude rapidamente todas as saídas para modo de impulso, contínuo ou electrofrog com um único comando DCC
- **Controlo por função de locomotiva** (F1–F16) — para comutação rápida com manípulos como o Roco Lokmaus ou Multimaus
- **Suporte de desvio de endereço Roco** — suporte integrado para o desvio de 4 endereços da Roco
- **Expansível com placas de relé e transístor:**
  - Módulo de relé duplo para polarização de agulha electrofrog
  - Relé de retenção simples para comutação de polaridade unifrog
  - Módulos de relé de contacto aberto para controlo DCC de relé de uso geral
  - Módulo driver de transístor para motores de agulha de dois fios

---

## 🔌 Ligar o Decoder

O OS-Solenoid-Decoder segue um esquema de cablagem claro e consistente. A alimentação é ligada no topo e as saídas ficam em ambos os lados.

---

## 🔋 Alimentação

- Ligue tensão de via DCC ou uma fonte de alimentação DC (máx. 19 V) ao decoder.
- Tanto o sinal DCC como os fios de alimentação ligam-se pelo lado superior do decoder.
- ⚠️ Não utilize tensão AC — isto danificará o decoder.

---
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

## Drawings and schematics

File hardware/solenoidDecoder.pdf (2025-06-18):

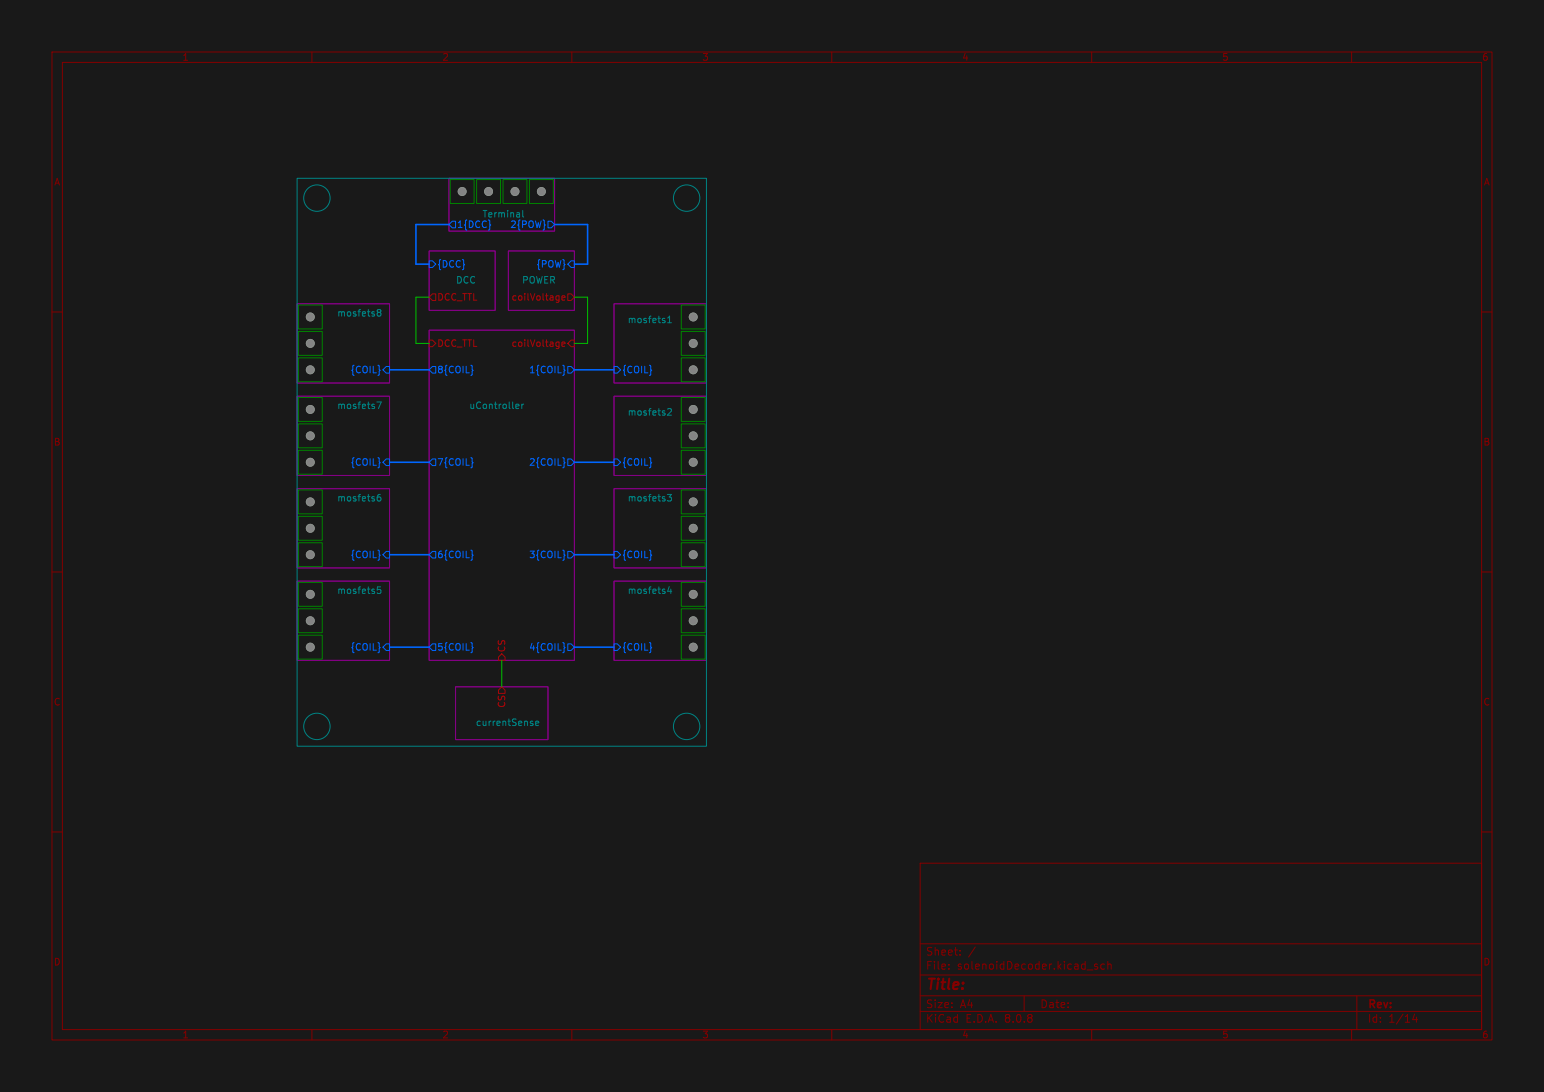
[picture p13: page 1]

Id: 1/14 Title: File: solenoidDecoder.kicad_sch Sheet: /

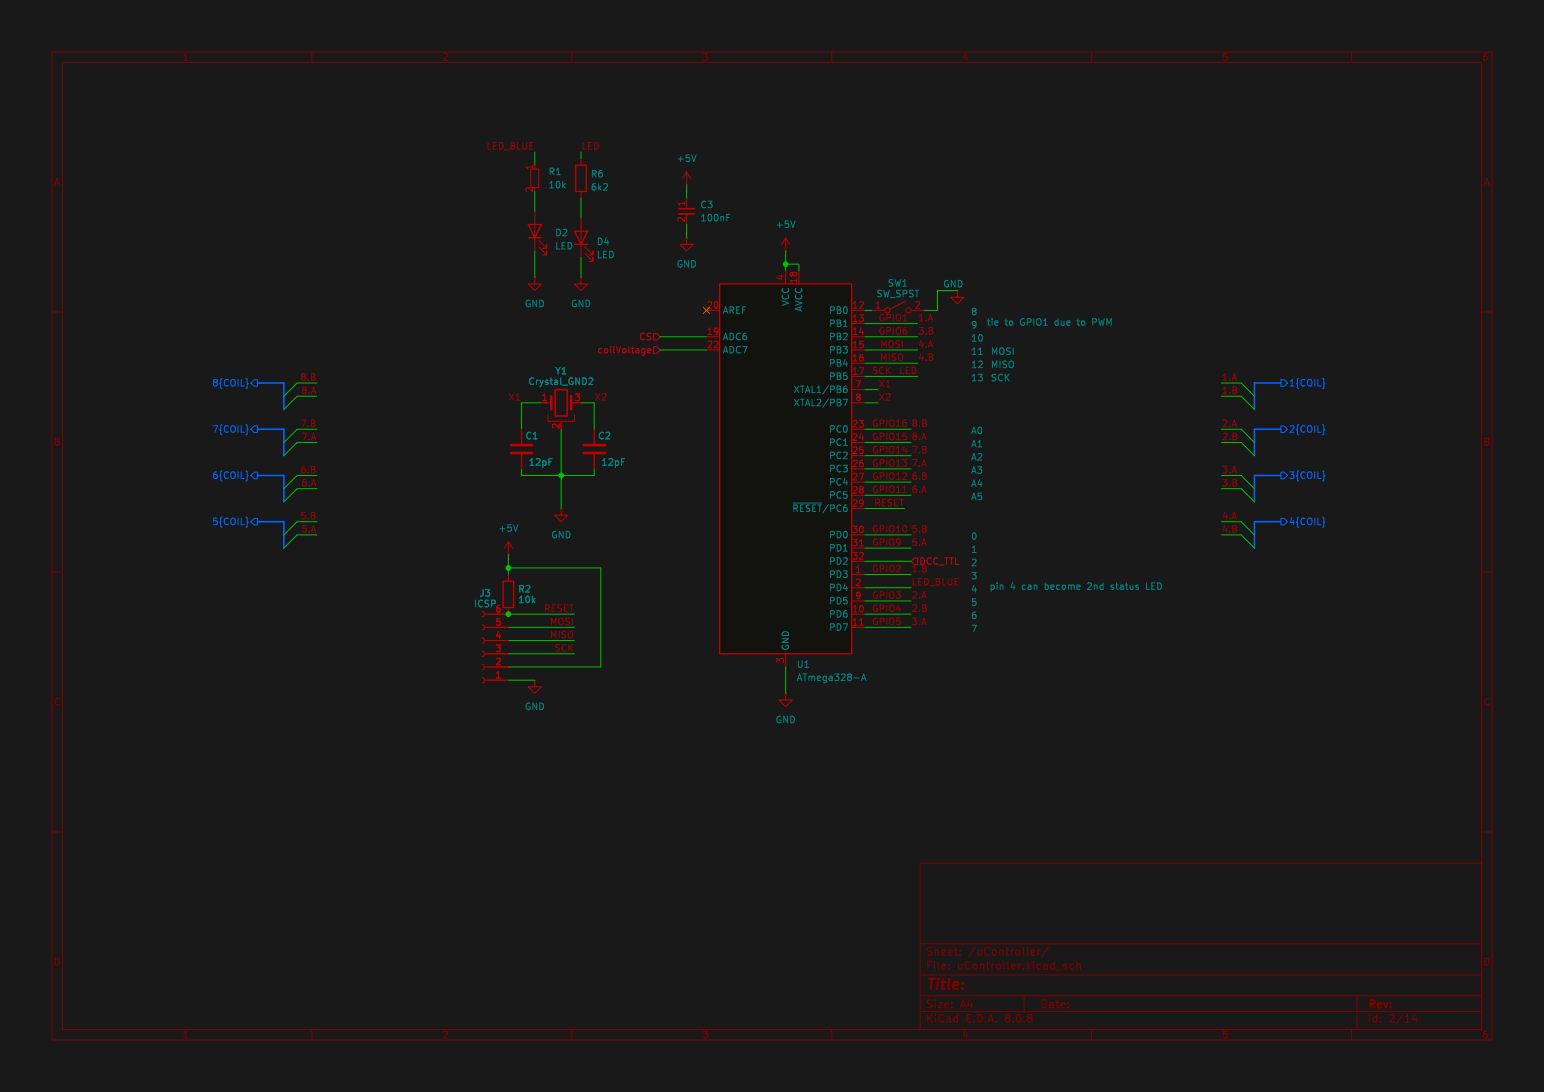
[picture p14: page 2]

pin 4 can become 2nd status LED

Id: 2/14 Title: File: uController.kicad_sch Sheet: /uController/

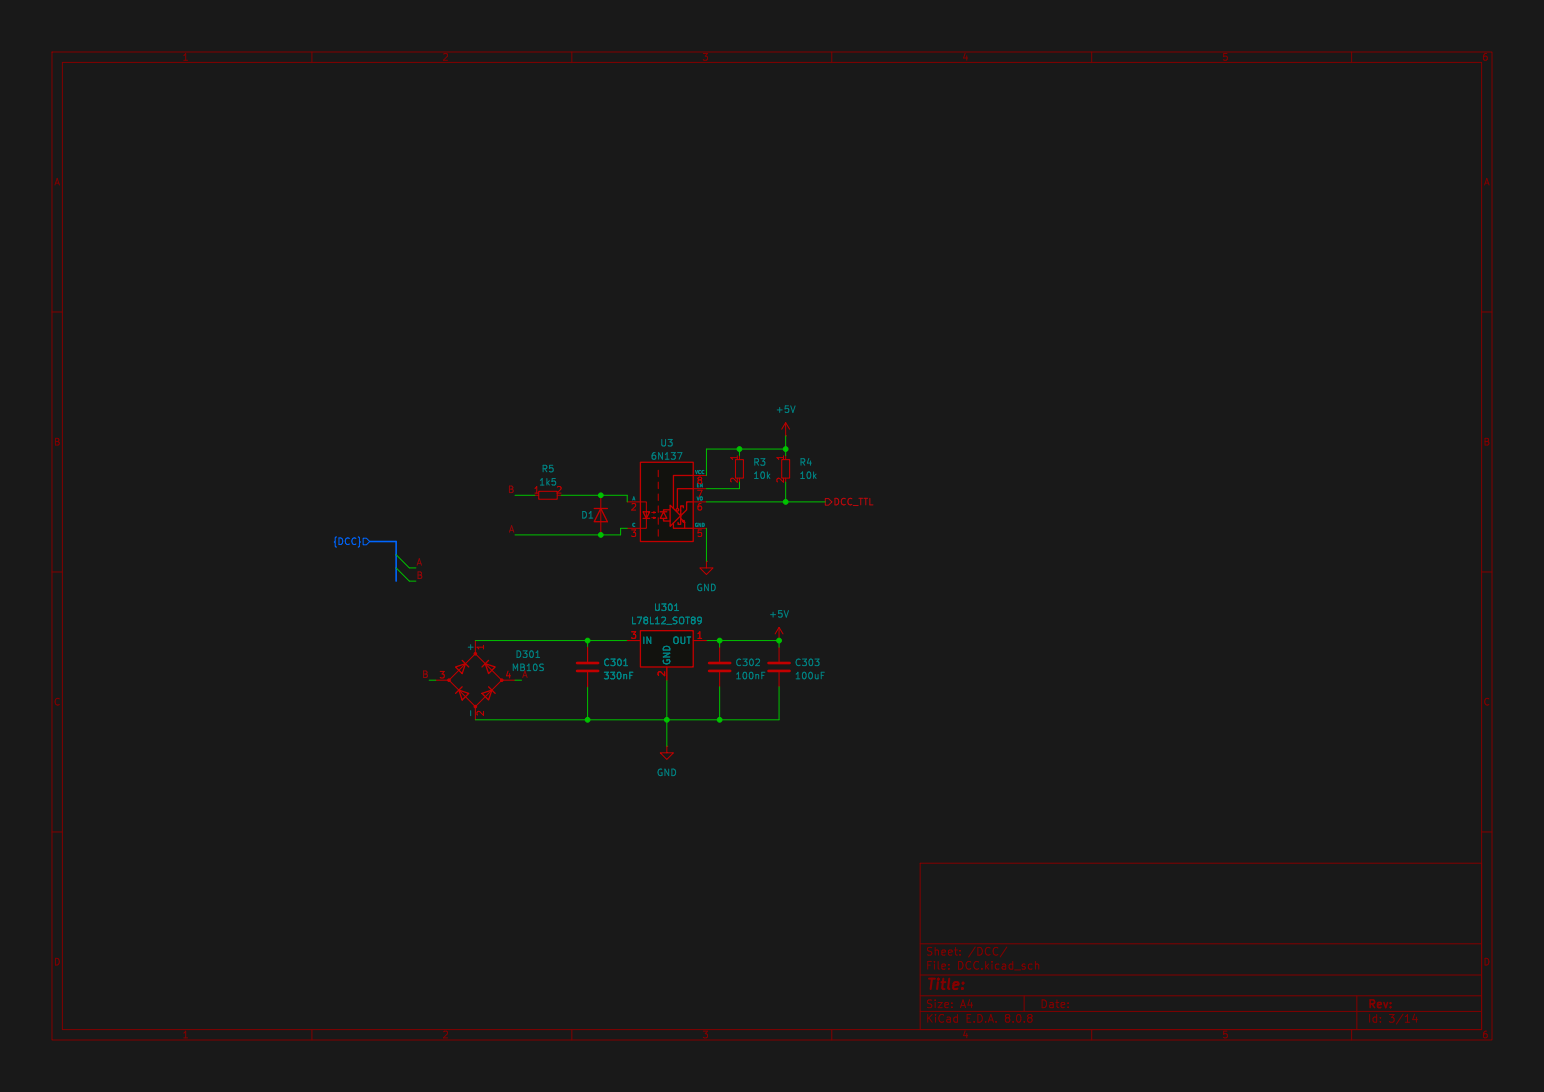
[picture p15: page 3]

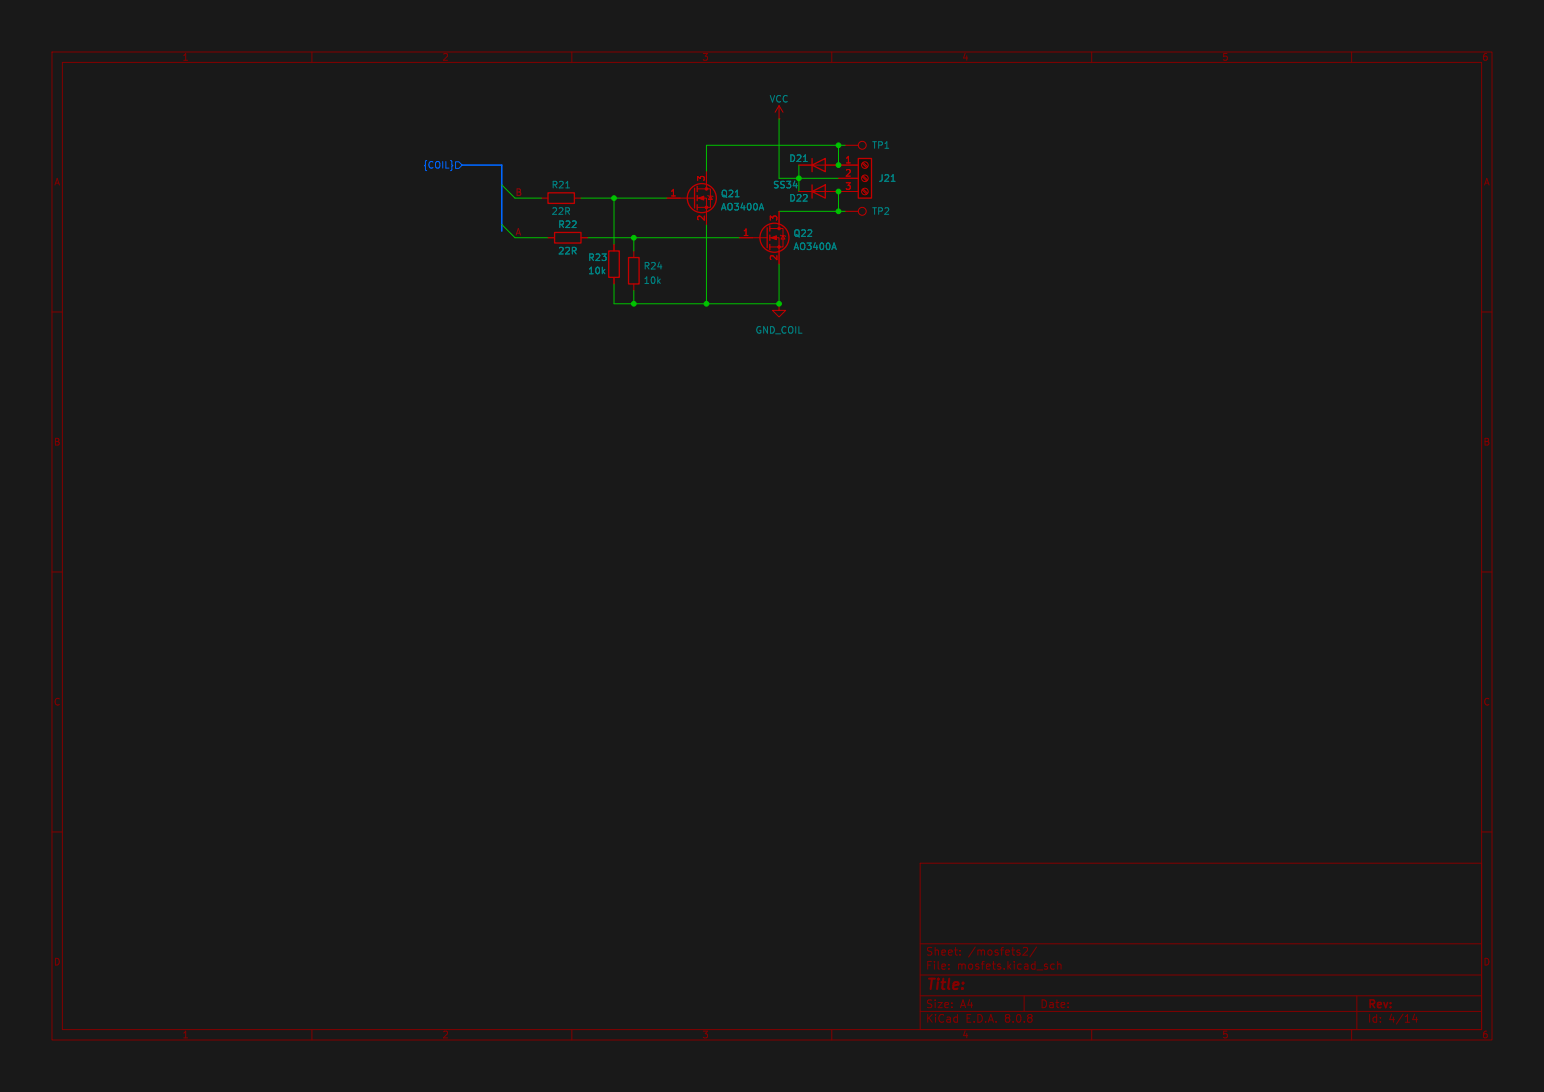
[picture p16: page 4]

Id: 4/14 Title: File: mosfets.kicad_sch Sheet: /mosfets2/

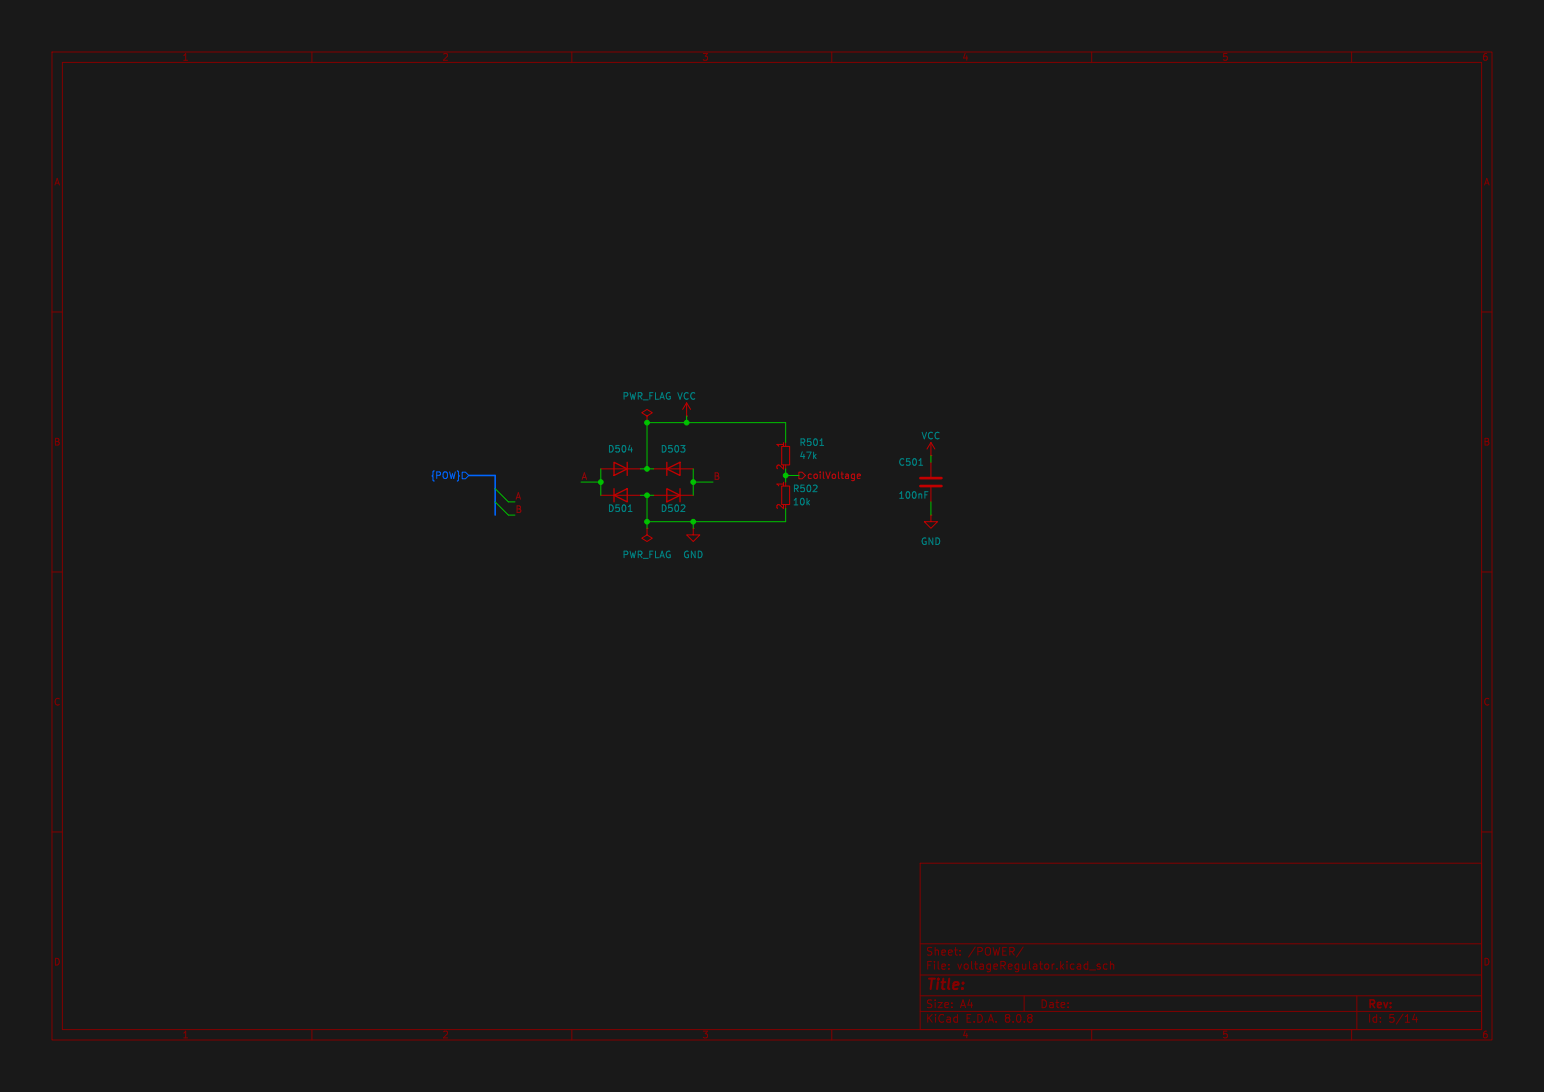
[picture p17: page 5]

Id: 5/14 Title: File: voltageRegulator.kicad_sch Sheet: /POWER/ GND

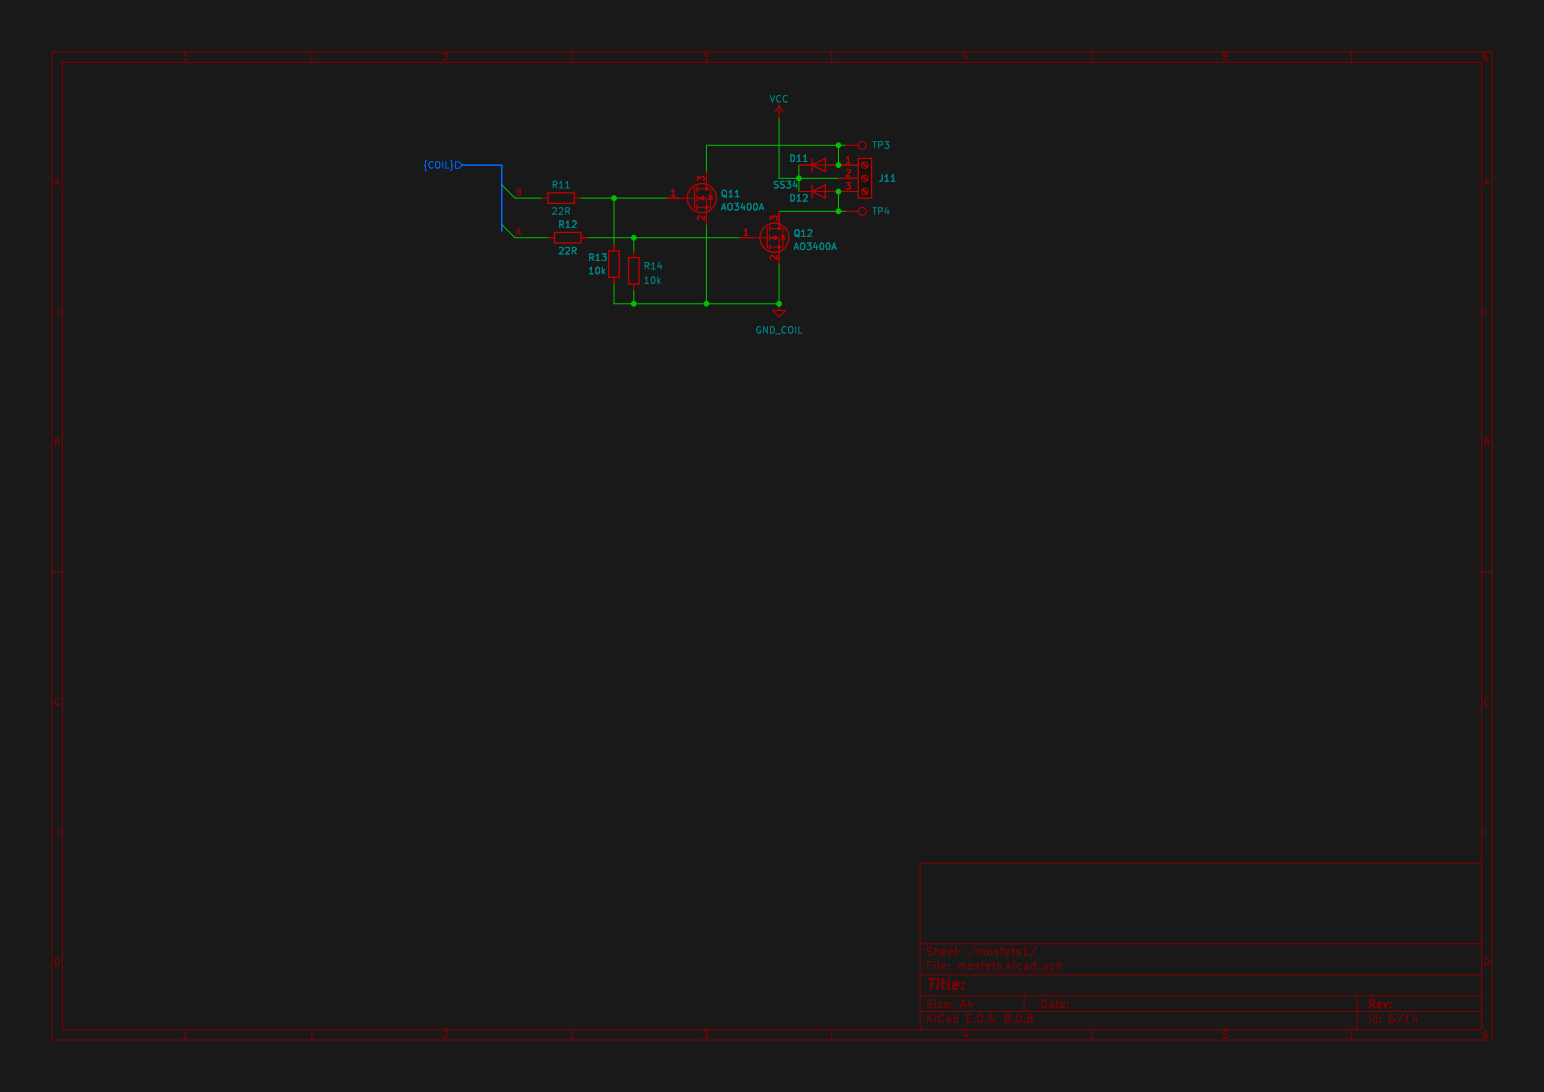
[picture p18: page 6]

Id: 6/14 Title: File: mosfets.kicad_sch Sheet: /mosfets1/

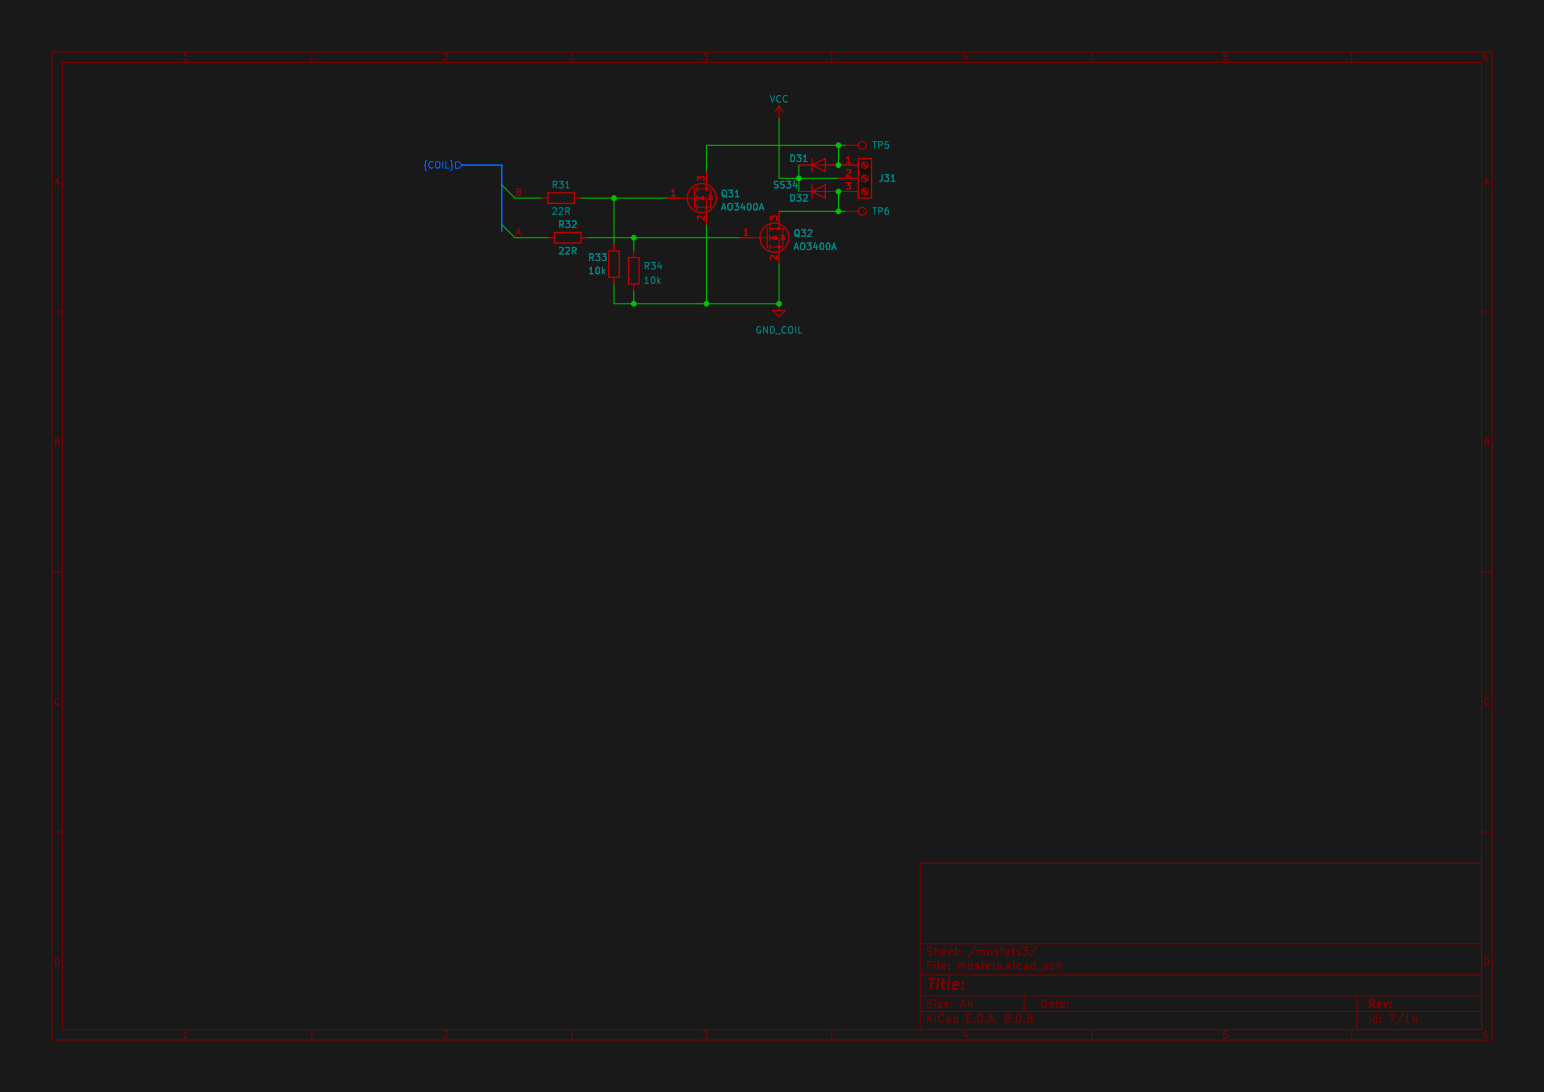
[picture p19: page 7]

Id: 7/14 Title: File: mosfets.kicad_sch Sheet: /mosfets3/

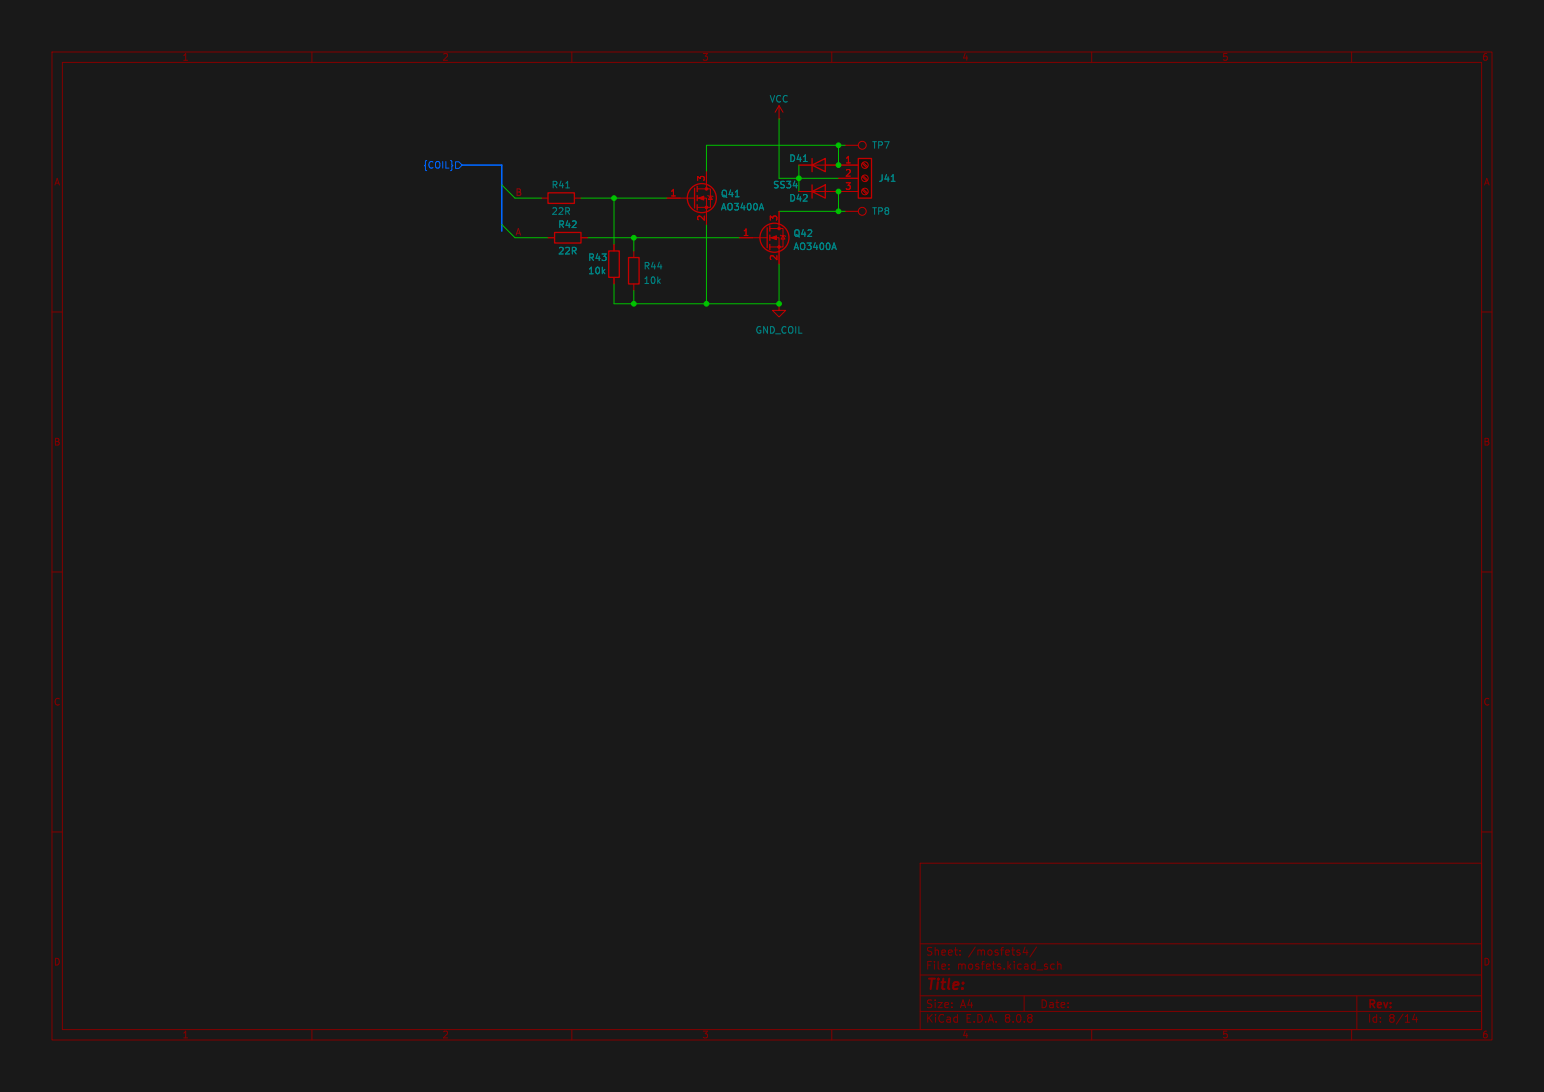
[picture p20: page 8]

Id: 8/14 Title: File: mosfets.kicad_sch Sheet: /mosfets4/

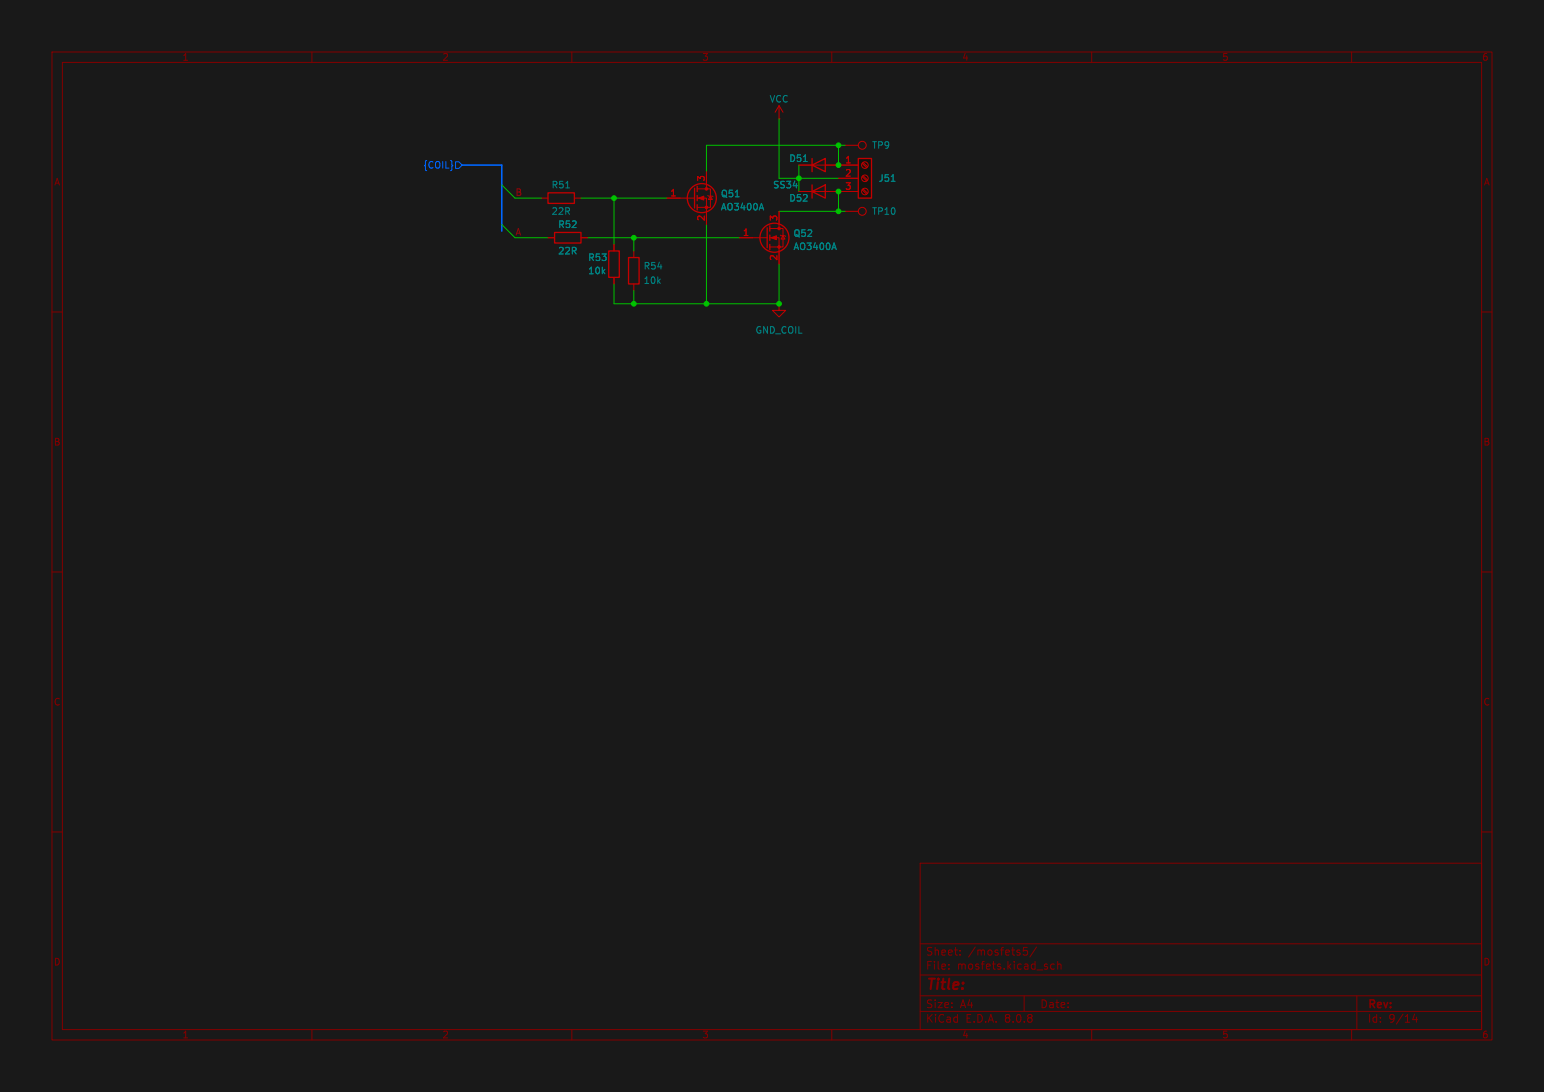
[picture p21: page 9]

Id: 9/14 Title: File: mosfets.kicad_sch Sheet: /mosfets5/

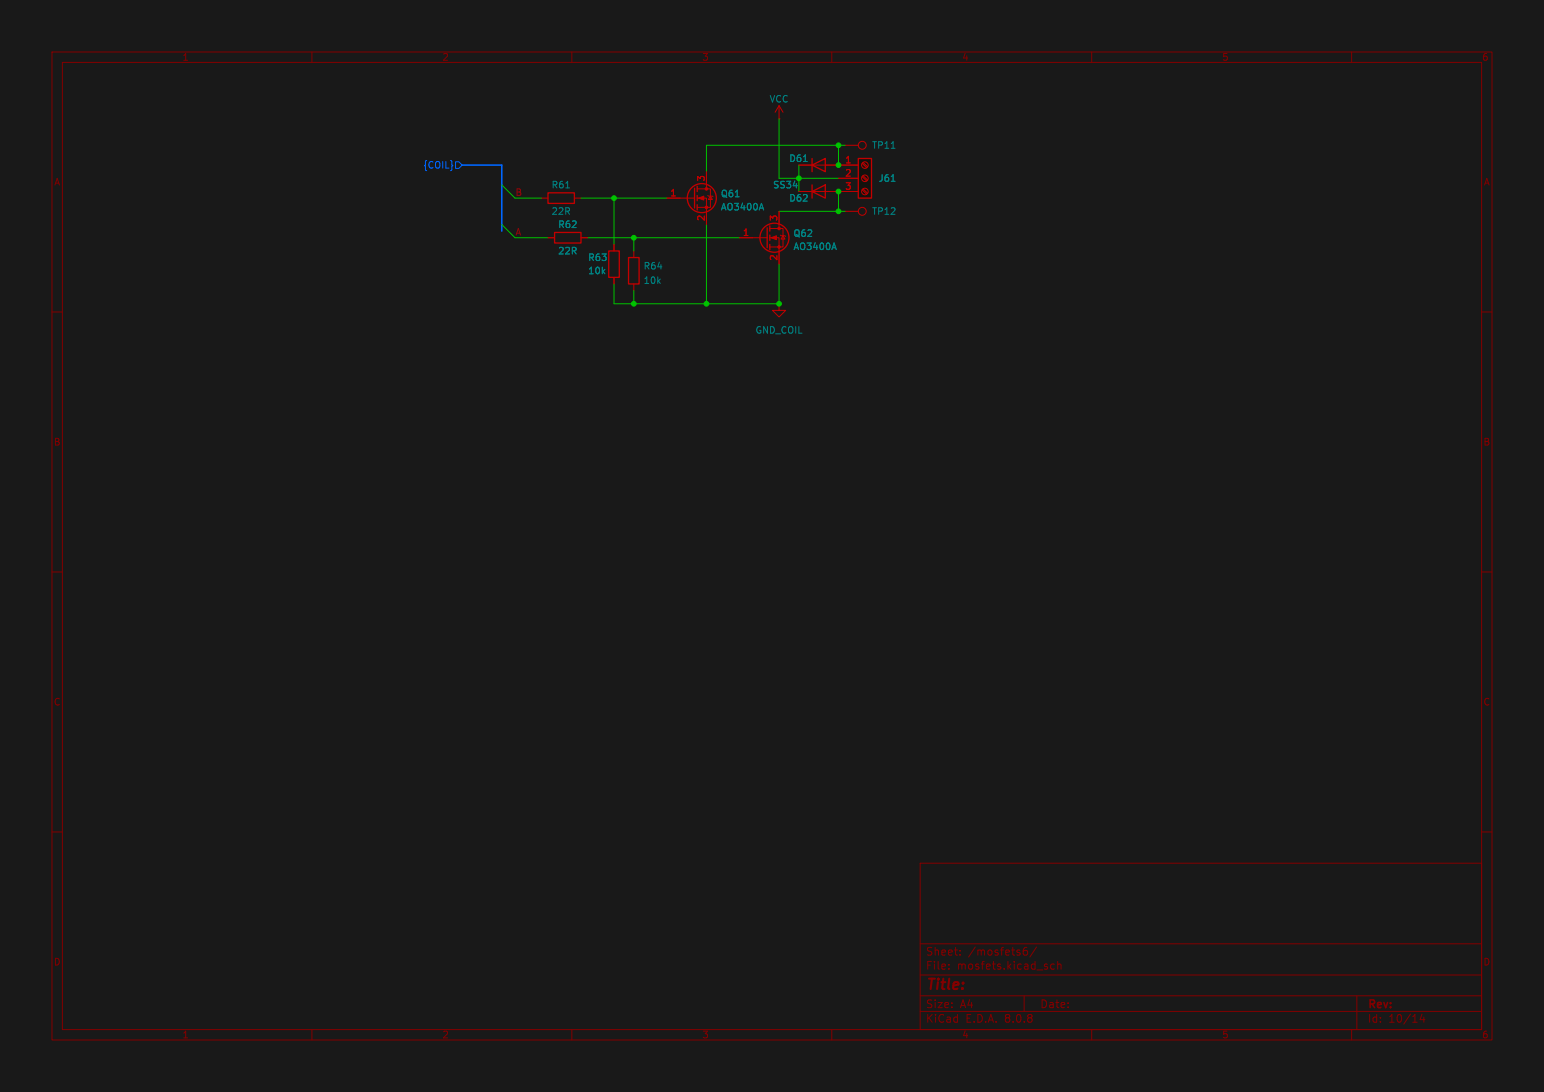
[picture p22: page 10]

Id: 10/14 Title: File: mosfets.kicad_sch Sheet: /mosfets6/

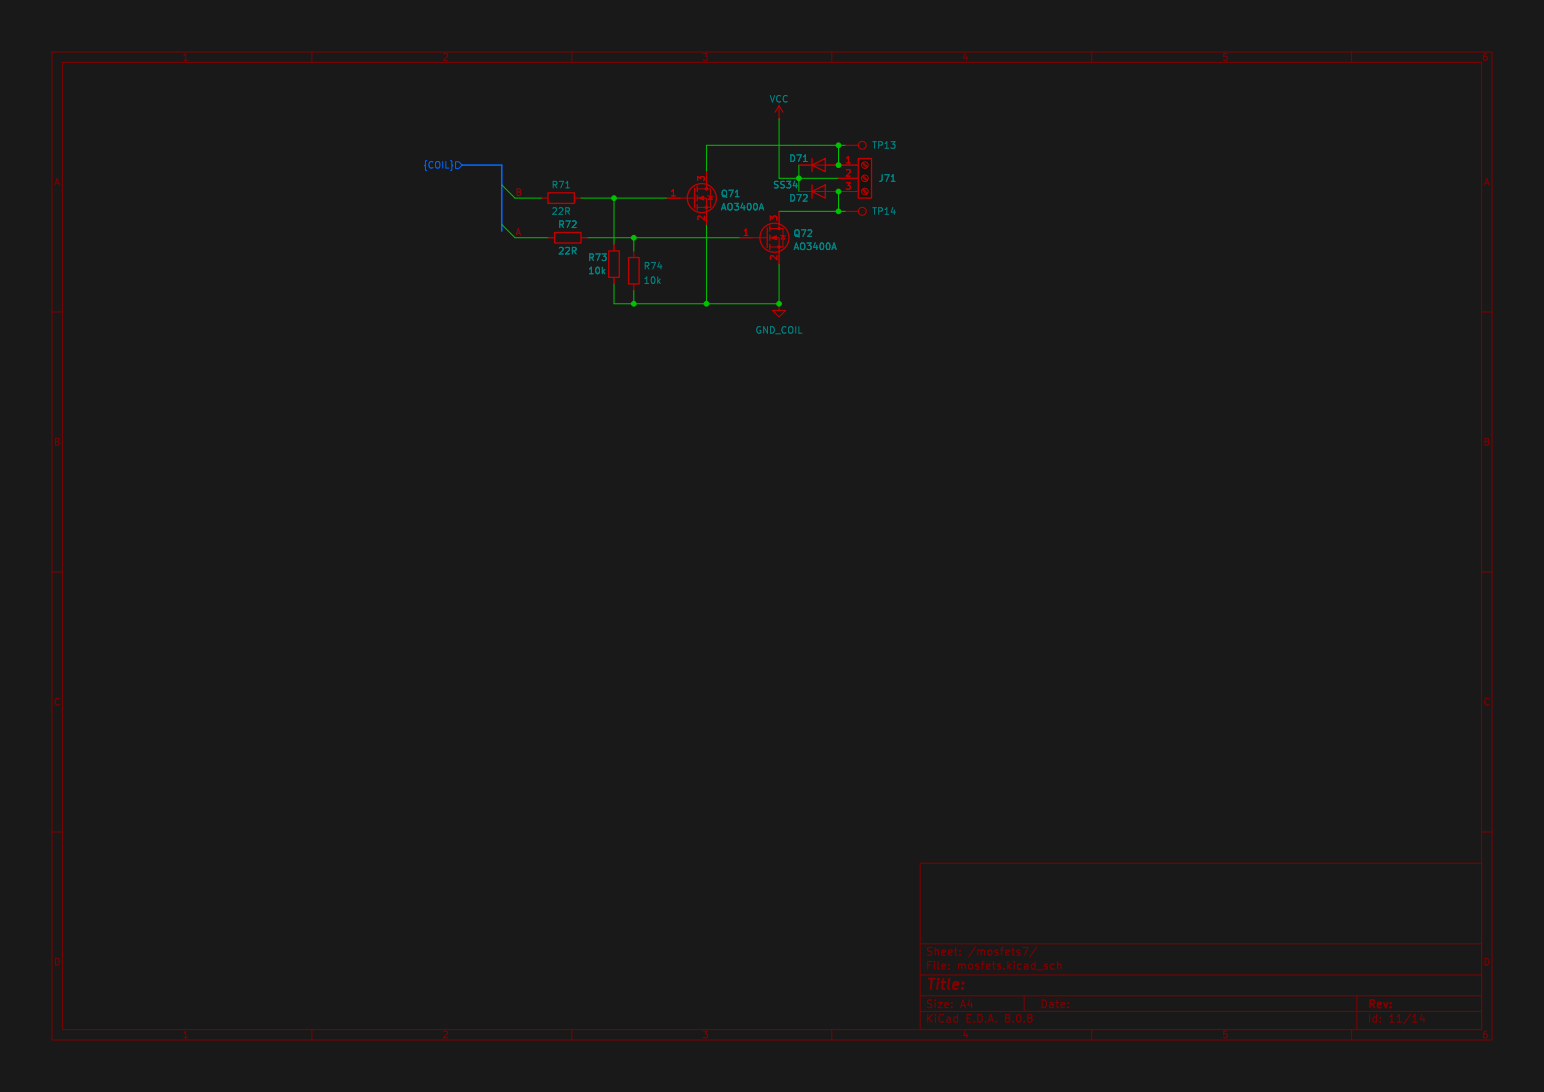
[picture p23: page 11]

Id: 11/14 Title: File: mosfets.kicad_sch Sheet: /mosfets7/

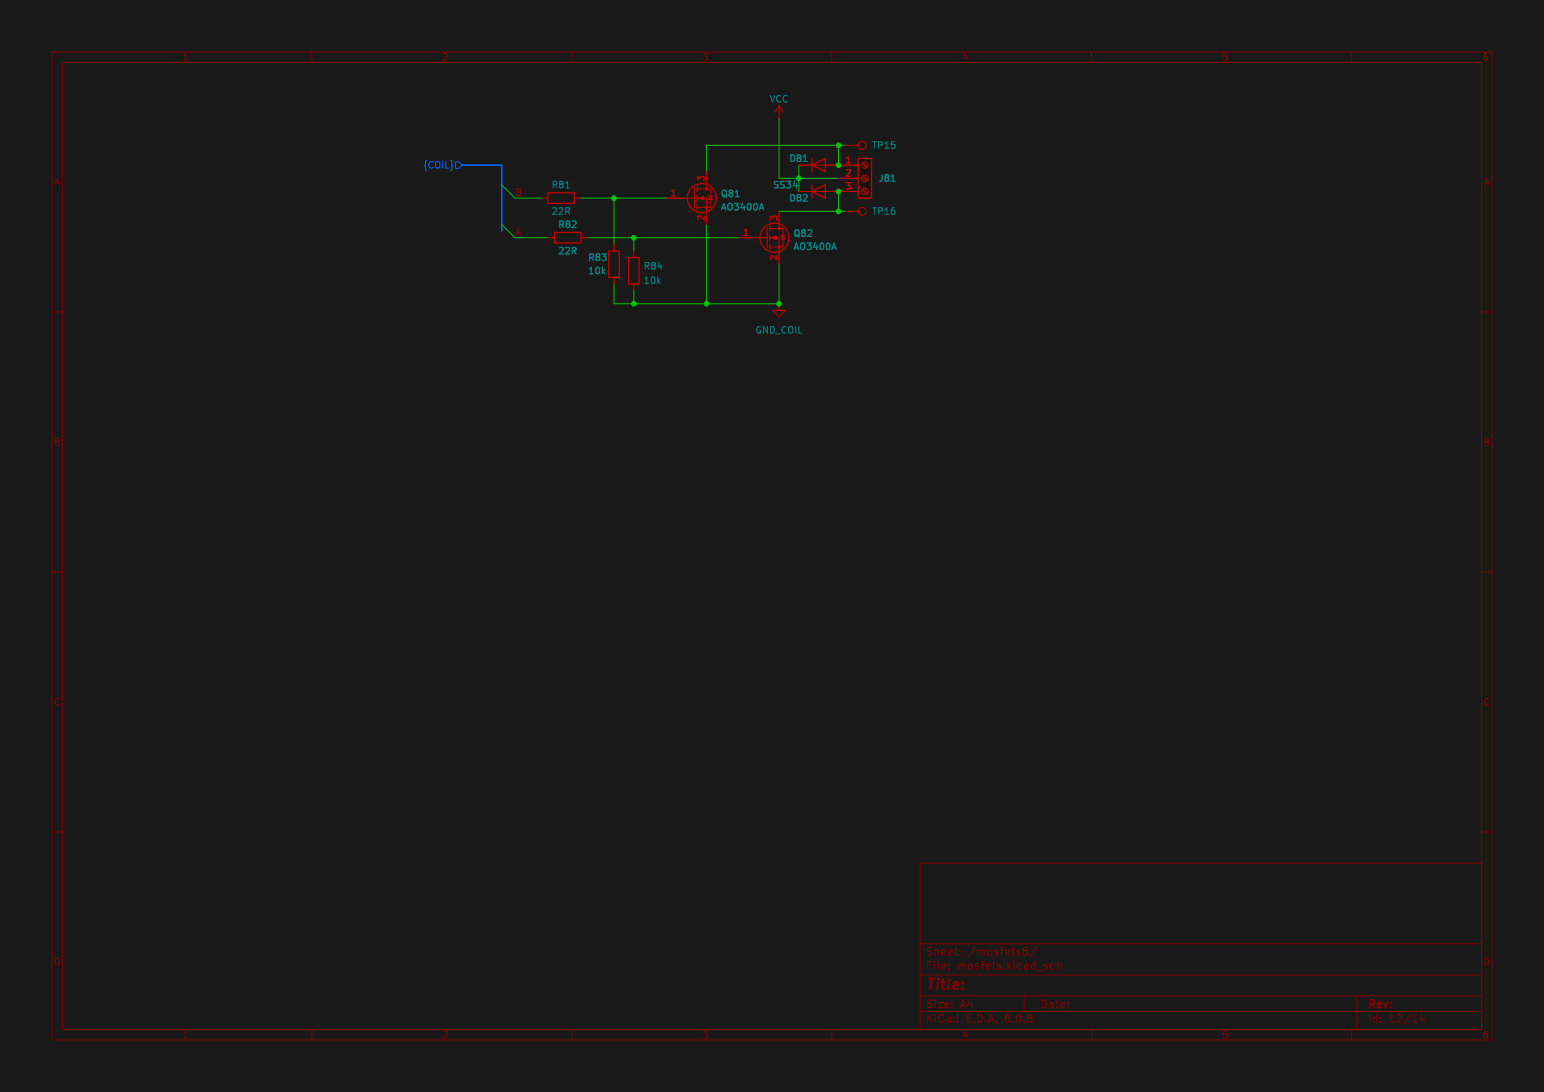
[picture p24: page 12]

Id: 12/14 Title: File: mosfets.kicad_sch Sheet: /mosfets8/


Id: 13/14 Title: File: Terminal.kicad_sch Sheet: /Terminal/


Id: 14/14 Title: File: currentSense.kicad_sch Sheet: /currentSense/ GND

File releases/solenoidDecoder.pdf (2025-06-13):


Id: 1/14 Title: File: solenoidDecoder.kicad_sch Sheet: /


pin 4 can become 2nd status LED

Id: 2/14 Title: File: uController.kicad_sch Sheet: /uController/


Id: 3/14 Title: File: DCC.kicad_sch Sheet: /DCC/ GND


Id: 4/14 Title: File: mosfets.kicad_sch Sheet: /mosfets2/


Id: 5/14 Title: File: voltageRegulator.kicad_sch Sheet: /POWER/


Id: 6/14 Title: File: mosfets.kicad_sch Sheet: /mosfets1/


Id: 7/14 Title: File: mosfets.kicad_sch Sheet: /mosfets3/


Id: 8/14 Title: File: mosfets.kicad_sch Sheet: /mosfets4/


Id: 9/14 Title: File: mosfets.kicad_sch Sheet: /mosfets5/


Id: 10/14 Title: File: mosfets.kicad_sch Sheet: /mosfets6/


Id: 11/14 Title: File: mosfets.kicad_sch Sheet: /mosfets7/


Id: 12/14 Title: File: mosfets.kicad_sch Sheet: /mosfets8/


Id: 13/14 Title: File: Terminal.kicad_sch Sheet: /Terminal/


Id: 14/14 Title: File: currentSense.kicad_sch Sheet: /currentSense/ GND

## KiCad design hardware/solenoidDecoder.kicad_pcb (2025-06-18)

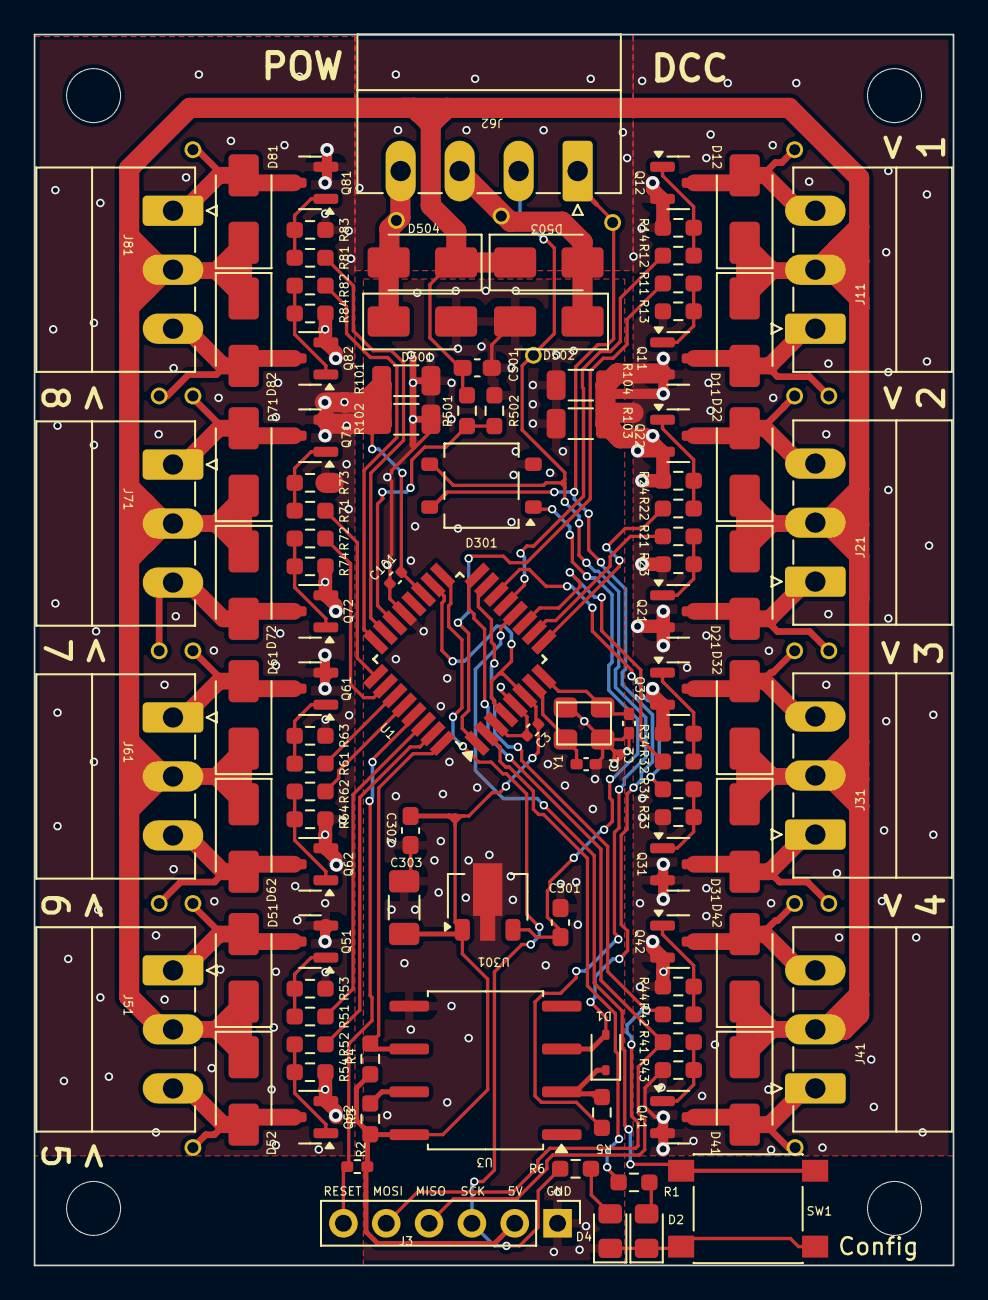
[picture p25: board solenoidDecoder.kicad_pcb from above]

Board: 2 copper layers, 54.5 x 73.0 mm, 127 parts (0 on the bottom side), 69 nets.

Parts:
C1, C2: 12pF; C_0402_1005Metric_Pad0.74x0.62mm_HandSolder
C3, C101: 100nF; C_0402_1005Metric
C301: 330nF; C_0603_1608Metric_Pad1.08x0.95mm_HandSolder
C302, C501: 100nF; C_0603_1608Metric_Pad1.08x0.95mm_HandSolder
C303: 100uF; C_1206_3216Metric_Pad1.33x1.80mm_HandSolder
D1: D; D_SOD-323
D2, D4: LED; LED_0805_2012Metric_Pad1.15x1.40mm_HandSolder
D11, D21, D31, D41, D51, D61, D71, D81: SS34; D_SMA
D12, D22, D32, D42, D52, D62, D72, D82: D_SMA
D301: MB10S; TO-269AA
D501, D502, D503, D504: SS53; D_SMA
J3: ICSP; PinHeader_1x06_P2.54mm_Vertical
J11, J21, J31, J41, J51, J61, J71, J81: PhoenixContact_MC_1,5_3-G-3.5_1x03_P3.50mm_Horizontal
J62: Screw_Terminal_01x04; PhoenixContact_MC_1,5_4-G-3.5_1x04_P3.50mm_Horizontal
Q11, Q12, Q21, Q22, Q31, Q32, Q41, Q42, Q51, Q52, Q61, Q62, Q71, Q72, Q81, Q82: AO3400A; SOT-23
R1, R3, R4, R502: 10k; R_0603_smalltext
R2: 10k; R_0402_1005Metric_Pad0.72x0.64mm_HandSolder
R5: 1k5; R_0603_smalltext
R6: 6k2; R_0603_1608Metric_Pad0.98x0.95mm_HandSolder
R11, R12, R21, R22, R31, R32, R41, R42, R51, R52, R61, R62, R71, R72, R81, R82: 22R; R_0603_1608Metric_Pad0.98x0.95mm_HandSolder
R13, R14, R23, R24, R33, R34, R43, R44, R53, R54, R63, R64, R73, R74, R83, R84: 10k; R_0603_1608Metric_Pad0.98x0.95mm_HandSolder
R101, R102, R103, R104: 0R1; R_1206_3216Metric
R501: 47k; R_0603_smalltext
SW1: SW_SPST; tactile_SMD_6mm
TP1, TP2, TP3, TP4, TP5, TP6, TP7, TP8, TP9, TP10, TP11, TP12, TP13, TP14, TP15, TP16, TP17, TP18, TP19, TP20: TestPoint; pogoTestPad
U1: ATmega328-A; TQFP-32_7x7mm_P0.8mm
U3: 6N137; SOP-8_6.62x9.15mm_P2.54mm
U301: L78L05_SOT89; SOT-89-3
Y1: Crystal_GND2; crystal_arduino

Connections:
+5V: C3.1, C302.1, C303.1, J3.2, R2.1, R3.1, R4.1, U1.4 (VCC), U1.6 (VCC), U1.18 (AVCC), U3.8 (VCC), U301.1 (OUT)
/DCC/A: D1.2 (A), D301.4, J62.1, TP17.1, U3.3 (C)
/DCC/B: D301.3, J62.2, R5.1, TP18.1
/DCC/DCC_TTL: R4.2, U1.32 (PD2), U3.6 (VO)
/POWER/A: D501.1 (K), D504.2 (A), J62.4, TP19.1
/POWER/B: D502.1 (K), D503.2 (A), J62.3, TP20.1
/POWER/coilVoltage: R501.2, R502.1, U1.22 (ADC7)
/mosfets1/A: R12.1, U1.13 (PB1)
/mosfets1/B: R11.1, U1.1 (PD3)
/mosfets2/A: R22.1, U1.9 (PD5)
/mosfets2/B: R21.1, U1.10 (PD6)
/mosfets3/A: R32.1, U1.11 (PD7)
/mosfets3/B: R31.1, U1.14 (PB2)
/mosfets4/A: J3.5, R42.1, U1.15 (PB3)
/mosfets4/B: J3.4, R41.1, U1.16 (PB4)
/mosfets5/A: R52.1, U1.31 (PD1)
/mosfets5/B: R51.1, U1.30 (PD0)
/mosfets6/A: R62.1, U1.28 (PC5)
/mosfets6/B: R61.1, U1.27 (PC4)
/mosfets7/A: R72.1, U1.26 (PC3)
/mosfets7/B: R71.1, U1.25 (PC2)
/mosfets8/A: R82.1, U1.24 (PC1)
/mosfets8/B: R81.1, U1.23 (PC0)
/uController/LED: J3.3, R6.1, U1.17 (PB5)
/uController/LED_BLUE: R1.1, U1.2 (PD4)
/uController/RESET: J3.6, R2.2, U1.29 (~RESET/PC6)
/uController/X1: C1.2, U1.7 (XTAL1/PB6), Y1.1
/uController/X2: C2.2, U1.8 (XTAL2/PB7), Y1.3
GND: C1.1, C2.1, C3.2, C101.2, C301.2, C302.2, C303.2, C501.2, D2.1 (K), D4.1 (K), D301.2 (-), D501.2 (A), D502.2 (A), J3.1, R101.2, R102.2, R103.2, R104.2, R502.2, SW1.2 (B), U1.3 (GND), U1.5 (GND), U1.21 (GND), U3.5 (GND), U301.2 (GND), Y1.2 (GND), Y1.4 (GND)
GND_COIL: C101.1, Q11.2 (S), Q12.2 (S), Q21.2 (S), Q22.2 (S), Q31.2 (S), Q32.2 (S), Q41.2 (S), Q42.2 (S), Q51.2 (S), Q52.2 (S), Q61.2 (S), Q62.2 (S), Q71.2 (S), Q72.2 (S), Q81.2 (S), Q82.2 (S), R13.1, R14.1, R23.1, R24.1, R33.1, R34.1, R43.1, R44.1, R53.1, R54.1, R63.1, R64.1, R73.1, R74.1, R83.1, R84.1, R101.1, R102.1, R103.1, R104.1, U1.19 (ADC6)
unnamed: D1.1 (K), R5.2, U3.2 (A)
unnamed: D2.2 (A), R1.2
unnamed: D4.2 (A), R6.2
unnamed: D11.2 (A), J11.1, Q11.3 (D), TP3.1
unnamed: D12.2 (A), J11.3, Q12.3 (D), TP4.1
unnamed: D21.2 (A), J21.1, Q21.3 (D), TP1.1
unnamed: D22.2 (A), J21.3, Q22.3 (D), TP2.1
unnamed: D31.2 (A), J31.1, Q31.3 (D), TP5.1
unnamed: D32.2 (A), J31.3, Q32.3 (D), TP6.1
unnamed: D41.2 (A), J41.1, Q41.3 (D), TP7.1
unnamed: D42.2 (A), J41.3, Q42.3 (D), TP8.1
unnamed: D51.2 (A), J51.1, Q51.3 (D), TP9.1
unnamed: D52.2 (A), J51.3, Q52.3 (D), TP10.1
unnamed: D61.2 (A), J61.1, Q61.3 (D), TP11.1
unnamed: D62.2 (A), J61.3, Q62.3 (D), TP12.1
unnamed: D71.2 (A), J71.1, Q71.3 (D), TP13.1
unnamed: D72.2 (A), J71.3, Q72.3 (D), TP14.1
unnamed: D81.2 (A), J81.1, Q81.3 (D), TP15.1
unnamed: D82.2 (A), J81.3, Q82.3 (D), TP16.1
unnamed: C301.1, D301.1 (+), U301.3 (IN)
unnamed: Q11.1 (G), R11.2, R13.2
unnamed: Q12.1 (G), R12.2, R14.2
unnamed: Q21.1 (G), R21.2, R23.2
unnamed: Q22.1 (G), R22.2, R24.2
unnamed: Q31.1 (G), R31.2, R33.2
unnamed: Q32.1 (G), R32.2, R34.2
unnamed: Q41.1 (G), R41.2, R43.2
unnamed: Q42.1 (G), R42.2, R44.2
unnamed: Q51.1 (G), R51.2, R53.2
unnamed: Q52.1 (G), R52.2, R54.2
unnamed: Q61.1 (G), R61.2, R63.2
unnamed: Q62.1 (G), R62.2, R64.2
unnamed: Q71.1 (G), R71.2, R73.2
unnamed: Q72.1 (G), R72.2, R74.2
unnamed: Q81.1 (G), R81.2, R83.2
unnamed: Q82.1 (G), R82.2, R84.2
unnamed: SW1.1 (A), U1.12 (PB0)
unnamed: R3.2, U3.7 (EN)
VCC: C501.1, D11.1 (K), D12.1 (K), D21.1 (K), D22.1 (K), D31.1 (K), D32.1 (K), D41.1 (K), D42.1 (K), D51.1 (K), D52.1 (K), D61.1 (K), D62.1 (K), D71.1 (K), D72.1 (K), D81.1 (K), D82.1 (K), D503.1 (K), D504.1 (K), J11.2, J21.2, J31.2, J41.2, J51.2, J61.2, J71.2, J81.2, R501.1

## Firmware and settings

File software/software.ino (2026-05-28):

#include "src/macros.h"
#include "src/NmraDcc.h"
#include "config.h"
#include "types.h"
#include "CoilDriver.h"
#include "CoilManager.h"
#include "ConfigMenu.h"
#include "DccCallbacks.h"
#include "pwm.h"
#include "src/debounceClass.h"
#include "src/ST.h"
#include <EEPROM.h>
#include "src/LedBlink.h"
#include "src/Logger.h"
#include "src/Simulator.h"



/******* SK NOTES **********

  Welcome to the new OSSD Mk2 source code.

LASTWORK:
I redid the PWM part to a more hardcoded approach. It need to be tested thoroughly.
coilClass now can handle it's own pulse timing. PWM for any pulsed type is therefor no longer possible.addressReceived


TODO:
The new PWM part need a solution to work with DORMENT outputs.

TEST EVERYTHING
rename yellow and blue led to leftLed and rightLed.  They're both red anyways  DONE

enforce faster update when an output is set. Especially a set coil has specific timing requirements. DONE, TEST ME!


BRAINWAVES:
We could also let coil class handle it's own pulse timer for pulsed outputs and reserve PWM especially for steady outputs DONE, TEST ME!
Perhaps that the coilClass should only do it's own pulse timer for double pulse timer, for single types it is not that important. DONE TEST ME


*/




// ── Global objects ────────────────────────────────────────────────────────────
NmraDcc     dcc ;
CoilDriver  coil[nCoils] ;
Debounce    configButton ;
Logger      logger ;
Simulator   sim ;
LedBlink    rightLed( rightLedPin ) ;
LedBlink    leftLed(  leftLedPin  ) ;
Timer       commitStates ;

// ── Settings ──────────────────────────────────────────────────────────────────
Settings defaultSettings =
{
    .uniqueAddresses = 0,
    .dccExt          = 0,
    .locoFunctions   = LOCO_FUNCTIONS_OFF,
    .maxCduVoltage   = 0,
    .hasCdu          = 0,
    .rcn213          = 1
} ;

Settings settings ;



// ── Config menu state ─────────────────────────────────────────────────────────
uint8_t              state     = idle ;
uint32_t             beginTime = 0 ;
uint8_t              coilIndex = 0 ;
volatile uint16_t    receivedAddress ;
volatile uint8_t     newAddressSet ;

// ── Runtime ───────────────────────────────────────────────────────────────────
uint8_t  runMode    = 1 ;
uint32_t lockoutTime ;

// ── Short-circuit ADC threshold  (5A @ 0.0125R shunt, 1024 steps, 5V ref) ────
static const uint8_t  R_shunt = 125 ;
static const uint8_t  I_max   =   5 ;
static const uint16_t V_max   = (uint16_t)R_shunt * I_max ;
static const uint8_t  ADC_max = ((uint32_t)1024 * V_max) / ((uint32_t)5 * 10000) ;

// ─────────────────────────────────────────────────────────────────────────────

void determineLedPattern()
{
    uint8_t currentPreset = getPreset() ;

    if( state == idle ) switch( currentPreset )
    {
        case DOUBLE_COIL_PULSED:        rightLed.bleep(  1 ) ; leftLed.bleep(  1 ) ; break ; // both bleep
        case DOUBLE_COIL_CONTINUOUSLY:  rightLed.turn(  ON ) ; leftLed.turn(  ON ) ; break ; // both on
        case SINGLE_COIL_PULSED:        rightLed.turn( OFF ) ; leftLed.bleep(  1 ) ; break ; //  1 bleep
        case SINGLE_COIL_CONTINUOUSLY:  rightLed.turn( OFF ) ; leftLed.turn(  ON ) ; break ; //  1 on
        case DOUBLE_PULSE_W_FROG:       rightLed.turn(  ON ) ; leftLed.bleep(  2 ) ; break ; // 1 on + 2 bleeps
        default:                        rightLed.bleep(  1 ) ; leftLed.turn(  ON ) ; break ; // 1 bleep + 1 on
    }

    else switch( state )
    {
        case checkButton:           rightLed.turn( OFF ) ; leftLed.turn( OFF ) ;        break ;

        case setIndex4Address:      rightLed.bleep( 1 ) ; leftLed.turn( OFF ) ; break ;
        case setIndex4Type:         rightLed.bleep( 2 ) ; leftLed.turn( OFF ) ; break ;
        case setIndex4pulse:        rightLed.bleep( 3 ) ; leftLed.turn( OFF ) ; break ;
        case setIndex4dutyCycle:    rightLed.bleep( 4 ) ; leftLed.turn( OFF ) ; break ;
        case configMode:            rightLed.bleep( 5 ) ; leftLed.turn( OFF ) ; break ;

        case setBaseAddress:        rightLed.bleep( 1 ) ; leftLed.turn( ON ) ; break ;
        case setUniqueAddress:      rightLed.bleep( 1 ) ; leftLed.turn( ON ) ; break ;
        case setCoilType:           rightLed.bleep( 2 ) ; leftLed.turn( ON ) ; break ;
        case setPulseTime:          rightLed.bleep( 3 ) ; leftLed.turn( ON ) ; break ;
        case setDutyCycle_:         rightLed.bleep( 4 ) ; leftLed.turn( ON ) ; break ;
    }
}

void saveStates()
{
    if( commitStates.update(1) )
        saveCoils() ;
}

void updateCduVoltage()
{
    static Timer timer ;
    static bool  timerInit = false ;
    if( !timerInit ) { timer.set( TIMER_BLEEP, 2000 ) ; timerInit = true ; }
    if( timer.update(1) )
    {
        uint16_t voltage = analogRead( coilVoltagePin ) ;
        if( voltage > settings.maxCduVoltage + 3 )
        {
            settings.maxCduVoltage = voltage ;
            EEPROM.put( EE_SETTINGS, settings ) ;
        }
    }
}

uint8_t deadbeef()
{
    const int DEADBEEF_EE_ADDRESS = 1020 ;
    uint32_t  DEADBEEF ;
    EEPROM.get( DEADBEEF_EE_ADDRESS, DEADBEEF ) ;

    if( DEADBEEF != 0xDEADBEEF )
    {   DEADBEEF  = 0xDEADBEEF ;
        EEPROM.put( DEADBEEF_EE_ADDRESS, DEADBEEF ) ;
        return 1 ;
    }
    return 0 ;
}

void notifyLog( const __FlashStringHelper* name, uint32_t value )
{
    Serial.print( name ) ;
    Serial.print( F(" -> ") ) ;
    Serial.println( value ) ;
}

// ─────────────────────────────────────────────────────────────────────────────

void setup()
{
    Serial.begin( 115200 ) ;

    commitStates.set( TIMER_BLEEP, 1000 ) ;
    configButton.begin( configPin ) ;

    for( int i = 0 ; i < nGpio ; i ++ )
    {
        pinMode( GPIO[i], OUTPUT ) ;
    }

    logger.SUBSCRIBE_BOOL( digitalRead( GPIO[ 0] ), "GPIO01" ) ;
    logger.SUBSCRIBE_BOOL( digitalRead( GPIO[ 1] ), "GPIO02" ) ;
    logger.SUBSCRIBE_BOOL( digitalRead( GPIO[ 2] ), "GPIO03" ) ;
    logger.SUBSCRIBE_BOOL( digitalRead( GPIO[ 3] ), "GPIO04" ) ;
    logger.SUBSCRIBE_BOOL( digitalRead( GPIO[ 4] ), "GPIO05" ) ;
    logger.SUBSCRIBE_BOOL( digitalRead( GPIO[ 5] ), "GPIO06" ) ;
    logger.SUBSCRIBE_BOOL( digitalRead( GPIO[ 6] ), "GPIO07" ) ;
    logger.SUBSCRIBE_BOOL( digitalRead( GPIO[ 7] ), "GPIO08" ) ;
    logger.SUBSCRIBE_BOOL( digitalRead( GPIO[ 8] ), "GPIO09" ) ;
    logger.SUBSCRIBE_BOOL( digitalRead( GPIO[ 9] ), "GPIO10" ) ;
    logger.SUBSCRIBE_BOOL( digitalRead( GPIO[10] ), "GPIO11" ) ;
    logger.SUBSCRIBE_BOOL( digitalRead( GPIO[11] ), "GPIO12" ) ;
    logger.SUBSCRIBE_BOOL( digitalRead( GPIO[12] ), "GPIO13" ) ;
    logger.SUBSCRIBE_BOOL( digitalRead( GPIO[13] ), "GPIO14" ) ;
    logger.SUBSCRIBE_BOOL( digitalRead( GPIO[14] ), "GPIO15" ) ;
    logger.SUBSCRIBE_BOOL( digitalRead( GPIO[15] ), "GPIO16" ) ;

    // sim.ADD(  100,  "hold config button",  digitalWrite( configPin, LOW  ) ) ;  // 1
    // sim.ADD( 3500,  "release button",       digitalWrite( configPin, HIGH ) ) ;  // 2
    // sim.ADD(  200,  "send DCC address 1",   notifyDccAccTurnoutOutput( 1, 1, 1 ) ) ; // 3

    rightLed.begin() ;
     leftLed.begin() ;

    if( deadbeef() )
    {
        EEPROM.put( EE_SETTINGS, defaultSettings ) ;

        for( int i = 0 ; i < nCoils ; i ++ )
        {
            coil[i].setType(      DOUBLE_COIL_PULSED        ) ;
            coil[i].setPulseTime( DEF_DOUBLE_PULSE_TIME     ) ;
            coil[i].setAddress(   i + 1                     ) ;
            coil[i].setDutyCycle( DEF_DUTYCYCLE             ) ;
            coil[i].setStates(    0, 0                      ) ;
        }
        saveCoils() ;
    }

    EEPROM.get( EE_SETTINGS, settings ) ;
    loadCoils() ;

    dcc.pin( 2, 0 ) ;
    dcc.init( MAN_ID_DIY, 11, FLAGS_OUTPUT_ADDRESS_MODE | FLAGS_DCC_ACCESSORY_DECODER, 0 ) ;
}


void loop()
{
    logger.Log() ;
    sim.Run() ;

    determineLedPattern() ;
    rightLed.update() ;
     leftLed.update() ;

    updatePwm() ;
    dcc.process() ;
    config() ;

    REPEAT_MS( 1 )
    {
        int sample = analogRead( currentSensePin ) ;
        if( sample >= ADC_max )
        {
            for( int i = 0 ; i < nGpio ; i ++ )
                digitalWrite( GPIO[i], LOW ) ; // kill all outputs

            rightLed.setEventBleeps( 5 ) ;
             leftLed.setEventBleeps( 5 ) ;

            runMode     = 0 ;
            lockoutTime = millis() ;
        }
    }
    END_REPEAT

    if( runMode == 0 && (millis() - lockoutTime) >= 5001 )
    {
        for( int i = 0 ; i < nCoils ; i++ ) coil[i].recover() ; // resync CoilDriver after GPIO kill
        runMode = 1 ;
    }

    if( runMode == 1 )
    {
        static uint8_t index     = 0 ;
        static bool    activated = false ;

        int voltage = analogRead( coilVoltagePin ) ;
        if( settings.hasCdu == 0
        ||  (!activated && voltage >= (settings.maxCduVoltage * 9 / 10)) ) activated = true ;

        if( activated )
        {
            if( coil[index].update() )
            {
                iterate( index, nCoils ) ;
                activated = false ;
            }
        }
    }

    saveStates() ;
    updateCduVoltage() ;
}

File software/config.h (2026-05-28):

#include <Arduino.h>

#ifndef CONFIG_H
#define CONFIG_H

const int nCoils        =  8 ;

const int GPIO[] =
{
     9,  3,  5,  6, // GPIO01-GPIO04
     7, 10, 11, 12, // GPIO05-GPIO08
     1,  0, A5, A4, // 1,0, A5, A4 GPIO09-GPIO12
    A3, A2, A1, A0, // GPIO13-GPIO16
} ;

const int DEF_SINGLE_PULSE_TIME     = 5000 ;
const int DEF_DOUBLE_PULSE_TIME     =   50 ;
const int DEF_DUTYCYCLE             =   10 ;
const int LOCKOUT_TIME              =  500 ;
const int nDccAddresses             = 2048 ;


// const int GPIO[] = // BAD ARRAY
// {
//     9,  2,  5,  6, // GPIO01-GPIO04
//      7, 10, 11, 12, // GPIO05-GPIO08
//     13, 4, A5, A4, // 1,0, A5, A4 GPIO09-GPIO12
//     A3, A2, A1, A0, // GPIO13-GPIO16
// } ;

const int nGpio         = 16 ;
const int configPin     =  8 ;
const int rightLedPin   =  4 ; 
const int leftLedPin    = 13 ;

const int currentSensePin = A6 ;
const int coilVoltagePin  = A7 ;

#endif

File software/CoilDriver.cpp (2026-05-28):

/*
 * Copyright (C) 2024 Sebastiaan Knippels, Train-Science
 *
 * To the extent possible under law, the person who associated CC0 with this work
 * has waived all copyright and related or neighboring rights to this work.
 *
 * This work is published from: The Netherlands
 *
 * You can copy, modify, distribute and perform the work, even for commercial purposes,
 * all without asking permission. See the full license for details at:
 * https://creativecommons.org/publicdomain/zero/1.0/
 */

// Written By: Sebastiaan Knippels. This library is public domain

#include "CoilDriver.h"
#include "pwm.h"

// double coil pulsed
// double coil continously
// single coil pulsed
// single coil Continously
// double coil pulsed, with frog relay (buddy pins)

const int OFF = 0 ;
const int  ON = 1 ;
const int   A = 0 ;
const int   B = 1 ;

CoilDriver::CoilDriver()
{
    buddyPinA = 0xFF ;
    buddyPinB = 0xFF ;
}

void CoilDriver::setBuddyPins( uint8 _B, uint8 _A ) // B is in front to mirror outputs deliberately
{
    buddyPinA = _A ;
    buddyPinB = _B ;
}

void CoilDriver::begin( uint8 _A, uint8 _B )
{
    pinA = _A ;
    pinB = _B ;
    lockoutTimer.set( TIMER_ON, 1000 ) ; // 'debounce' lockout time for repetetive DCC messages.
    trigA.arm() ;
    trigB.arm() ;
}

void CoilDriver::initializeCoils()
{
    if( type == DOUBLE_COIL_PULSED
    ||  type == SINGLE_COIL_PULSED
    ||  type == DOUBLE_PULSE_W_FROG )
    {
        turn( pinA, OFF ) ;
        turn( pinB, OFF ) ;
    }

    if( type == DOUBLE_PULSE_W_FROG )
    {
        digitalWrite( buddyPinA,  oldStateA ) ;
        digitalWrite( buddyPinB,  oldStateB ) ; 
    }

    if( type == SINGLE_COIL_CONTINUOUSLY
    ||  type == DOUBLE_COIL_CONTINUOUSLY )
    {
        state2beA = oldStateA ; // this will ensure that the ouput goes on
        state2beB = oldStateB ;
    }
}

void CoilDriver::reset()
{
    outputStateA = state2beA = oldStateA = 0 ;
    outputStateB = state2beB = oldStateB = 0 ;

    turn( pinA, OFF ) ;
    turn( pinB, OFF ) ;

    if( type == DOUBLE_PULSE_W_FROG )
    {
        digitalWrite( buddyPinA,  LOW ) ;
        digitalWrite( buddyPinB,  LOW ) ;
    }
}

const int         FREE = 0 ; 
const int IN_POSESSION = 1 ; 

void CoilDriver::turn( uint8 pin, uint8 newState )
{
    if( type == DOUBLE_COIL_PULSED      // double pulse only, directly set outputs for faster and more accurate response time
    ||  type == DOUBLE_PULSE_W_FROG )
    {
        digitalWrite( pin, newState ) ;
    }

    else                                // all other modes may make use of PWM
    {
        if( newState == 1 ) { subscribePwm( pin, dutycycle ) ; }
        else                { unsubscribePwm( pin ) ;          }
    }
}

uint8 CoilDriver::update()
{
    if( type == DORMENT )  return 1 ;

    if( lockoutTimer.update( lockout ) ) { lockout = 0 ; }
    
    static uint8_t sharedToken =  FREE ;

    // a double pulsed output require posession of the shared token before the outputs may be turned on.
    // The token prevents from more than one output being activated at the same time. This protects CDU, power supply, decoder and ensures no overcurrent is tripped.
    // The shared token is static by design and shared beteen all 8 coil objects.

    if( sharedToken == FREE   
    && (type == DOUBLE_PULSE_W_FROG || type == DOUBLE_COIL_PULSED)
    && (state2beA == 1 || state2beB == 1) )
    {
        sharedToken    =  IN_POSESSION ; 
        myToken        =  IN_POSESSION ;

        outputStateA   =  state2beA ;
        outputStateB   =  state2beB ;
        
        state2beA      = 0 ;
        state2beB      = 0 ;
    }

    // continuous types: desired state persists until a new command changes it
    if( type == SINGLE_COIL_CONTINUOUSLY || type == DOUBLE_COIL_CONTINUOUSLY )
    {
        outputStateA = state2beA ;
        outputStateB = state2beB ;
    }

    // single pulsed: latch new state only when output is idle, so an in-progress pulse is not interrupted
    if( type == SINGLE_COIL_PULSED )
    {
        if( outputStateA == 0 ) { outputStateA = state2beA ; state2beA = 0 ; }
        if( outputStateB == 0 ) { outputStateB = state2beB ; state2beB = 0 ; }
    }

    timerA.update( outputStateA ) ;
    timerB.update( outputStateB ) ;

    // single pulsed: timer terminates the pulse, no token involved
    if( type == SINGLE_COIL_PULSED )
    {
        if( timerA.Q ) { outputStateA = 0 ; }
        if( timerB.Q ) { outputStateB = 0 ; }
    }

    // double pulsed: token is released when both outputs go idle
    if( myToken == IN_POSESSION
    && (type == DOUBLE_COIL_PULSED || type == DOUBLE_PULSE_W_FROG) )
    {
        if( timerA.Q ) { outputStateA = 0 ; }
        if( timerB.Q ) { outputStateB = 0 ; }

        if( outputStateA == 0 && outputStateB == 0 )
        {
            myToken     = FREE ;
            sharedToken = FREE ;
        }
    }

    trigA.update( outputStateA ) ;
    trigB.update( outputStateB ) ;

    bool rArose = trigA.rose() ; // capture before buddy-pin section; rose()/fell() clear-on-read
    bool fAfell = trigA.fell() ;
    bool rBrose = trigB.rose() ;
    bool fBfell = trigB.fell() ;

    if( rArose ) { turn( pinA, ON  ) ; } // rising flank  -> set output
    if( rBrose ) { turn( pinB, ON  ) ; }
    if( fAfell ) { turn( pinA, OFF ) ; } // falling flank -> kill output
    if( fBfell ) { turn( pinB, OFF ) ; }

    // this part handles the buddy pins for DOUBLE_PULSE_W_FROG mode
    if( type == DOUBLE_PULSE_W_FROG )
    {
        if( rArose || rBrose )   // if either coil fires, de-energise both frog relay pins first
        {
            digitalWrite( buddyPinA, LOW ) ;
            digitalWrite( buddyPinB, LOW ) ;
        }

        if( fAfell ) { digitalWrite( buddyPinA, HIGH ) ; } // pulse finished -> latch the relay
        if( fBfell ) { digitalWrite( buddyPinB, HIGH ) ; }
    }

    if( type == DOUBLE_COIL_PULSED || type == DOUBLE_PULSE_W_FROG ) // double pulse coils, may only return true when deactivated.
    {
        if( outputStateA == 0 && outputStateB == 0 ) return 1 ;
        else                                         return 0 ;
    }

    else return 1 ;
}


uint8_t CoilDriver::setCoilExt( uint16 dccAddress, uint8 _aspect )
{
    if( type != SINGLE_COIL_PULSED ) return 0 ; // and 

    uint16    primaryAddress = myAddress ;
    uint16  secondaryAddress = primaryAddress + 1 ;
    uint32         pulseTime = _aspect * 1000 ; // aspect number is used for pulse length in seconds.

    if( dccAddress ==   primaryAddress ) { timerA.set( TIMER_ON, pulseTime ) ; state2beA = 1 ; return 1 ; }
    if( dccAddress == secondaryAddress ) { timerB.set( TIMER_ON, pulseTime ) ; state2beB = 1 ; return 1 ; }

    return 0 ;
}

// may become obsolete in favor of initialize IO.
void CoilDriver::setStates( uint8_t A, uint8_t B )
{
    oldStateA = A ;
    oldStateB = B ;
}
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

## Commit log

2025-06-13 Added initial files
    [BOM-front_panel.csv, DCC.kicad_sch, Terminal.kicad_sch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]
2025-06-18 organized board files and added pictures
    [BOM-front_panel.csv, DCC.kicad_sch, front_panel.kicad_pcb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]
2025-06-20 added flow chart for config menu
2025-07-18 updated manual with how to wire GP relay extention to be used as frog polaization
2025-10-27 removed obsolete build and upload files
    [BOM-solenoidDecoder.csv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]
2026-05-22 Made new logger and simulator tool. Also let Claude AI do some bugsquashing for me.
    [CoilDriver.cpp, LedBlink.cpp, pwm.cpp]
2026-05-28 Fix Simulator.cpp to match header — remove stale msgInFlash references
    Removed dead const char* add_ overload, removed msgInFlash field references
    from all AddEvent calls, and replaced PrintMsg with direct Serial.println
    on the __FlashStringHelper* message pointer. .cpp now matches Simulator.h.
2026-05-28 Add MTRANSITION (multi-branch conditional jump) to Simulator
    Adds MTRANSITION macro supporting 2-, 3-, and 4-way branches, guarded
    by #define TRANSITIONS_ENABLED (commented out by default, zero overhead).
    Also adds WAIT_SERIAL_COMMAND macro for serial-driven test flows.
2026-05-28 Refactor Logger to shared tick timer — saves 8 bytes per Watcher
    Removes per-watcher lastTime and interval fields. All VALUE watchers
    now share a single tick timer (default 100 ms / 10 Hz) in the Logger
    object. BOOL watchers are unaffected. Drops SUBSCRIBE_VAL_MS macro.
    Watcher shrinks from 17 to 9 bytes; net saving ~120 bytes for 16 watchers.
2026-05-28 Replace Trigger/Timers with unified ST library; migrate all usages
    - Add src/ST.h and src/ST.cpp (Timer + Trigger unified library)
    - Remove src/Trigger.h, src/Trigger.cpp, src/Timers.h, src/Timers.cpp
    - CoilDriver.h: R_trigger/F_trigger -> Trigger, T_ON -> Timer
    - CoilDriver.cpp: arm triggers in begin(), capture rose()/fell() before
    buddy-pin check, update setPulseTime/setCoilExt/recover to new API
    - ConfigMenu.cpp: R_trigger -> Trigger, arm on button press, use
    update()+rose() pattern in checkButton state
    - software.ino: BlinkTimer -> Timer with TIMER_BLEEP, use set() for init
    [CoilDriver.cpp, CoilManager.cpp, config.h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]
